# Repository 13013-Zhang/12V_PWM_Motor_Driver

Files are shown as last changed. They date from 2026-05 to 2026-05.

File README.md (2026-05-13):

# 12V DC Motor Driver Board (PWM)

> **University of Warwick · School of Engineering · ES2J1 Electrical and Electronic Design Project · 2025–2026**

A fully analogue, hardware-based educational PCB demonstrator for teaching PWM generation, DC/DC power conversion, and bidirectional DC motor control. No microcontroller or Arduino is used — all control is implemented in discrete analogue hardware.

---

## 📸 PCB Photos

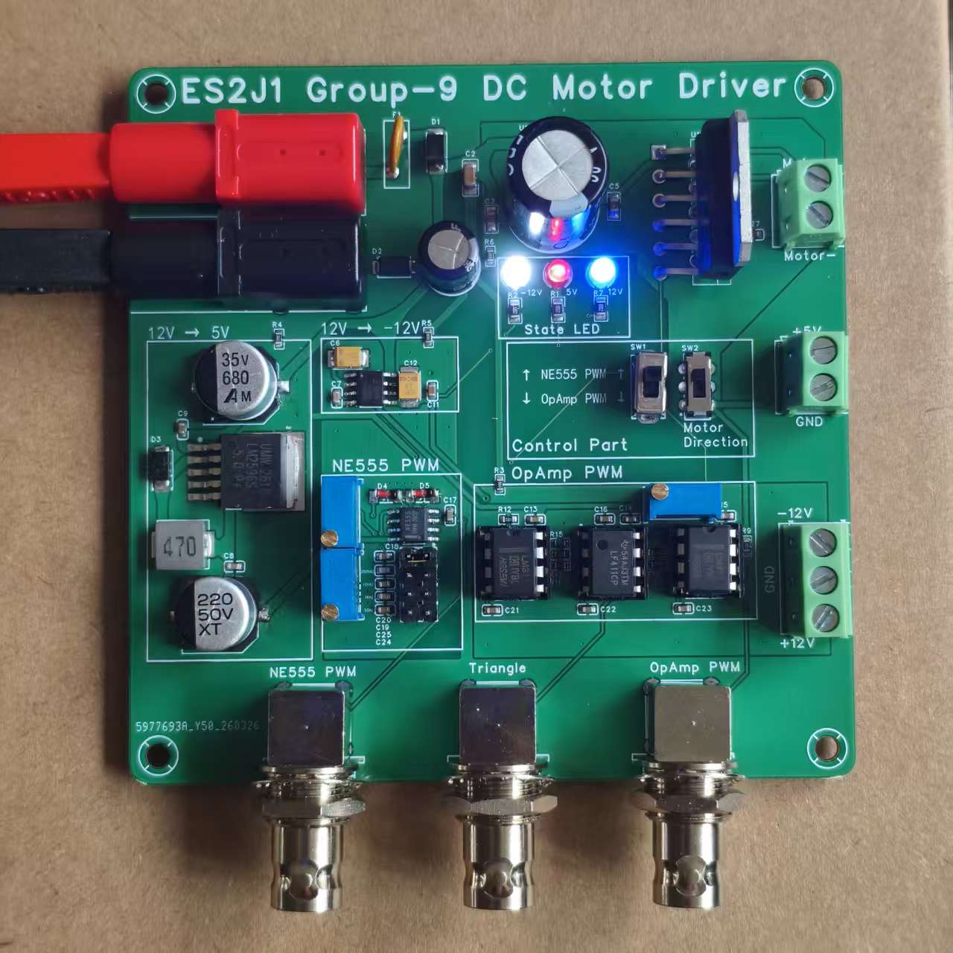
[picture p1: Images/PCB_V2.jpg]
PCB V2


---

## 🎯 Project Overview

This board was designed as a laboratory teaching tool for second-year undergraduate electrical and electronic engineering students. It integrates five functional sub-systems on a single custom 2-layer PCB, allowing students to observe, measure, and compare real hardware behaviour against theoretical predictions.

**Key design constraints met:**
- Single **+12V** supply input only
- **No microcontroller** — fully analogue PWM generation
- Custom PCB designed in **Altium Designer** (no commercial kits)
- Total component cost: **£173.36** (within £200 budget)
- Complies with **IPC-A-610G** soldering standards and **BS EN 61010** safety requirements

---

## 🗂️ Repository Structure

```
ES2J1_Group9_Motor_Driver/
│
├── PCB/
│   ├── ES2J1_Group9_Motor_Driver.PrjPcb      # Altium Designer project file
│   ├── ES2J1_Group9_Schematic.SchDoc         # Full schematic capture
│   ├── ES2J1_Group9_PCB.PcbDoc               # PCB layout and routing
│
├── Images/
│   ├── PCB_V1.jpg                        # Assembled PCB photo (V1)
│   └── PCB_V2.jpg                        # Assembled PCB photo (V2)
│
├── videos/                               # Test and demonstration videos
│   ├── NE555 OCR.mp4
│   ├── OpAmp OCR.mp4
│   ├── Simulation & Circuit.mp4
│   └── Simulation with Osc.mp4
│
└── README.md
```

---

## ⚙️ System Architecture

The board accepts a single **+12V / GND** input and generates all other required voltages on-board. Five sub-systems work together to drive and control a DC motor:

```
+12V Input
    │
    ├──► DC/DC Buck Converter (LM2596S-5.0) ──► +5V rail (NE555 supply)
    │
    ├──► Charge Pump (ICL7660AIBAZA-T) ──────► −12V rail (Op-Amp supply)
    │
    ├──► NE555 PWM Generator ─────────────────────┐
    │                                             ├──► H-Bridge (L6203) ──► DC Motor
    └──► Op-Amp PWM Generator (LF411CP / LM311N) ─┘
              (selectable via SW1)
```

### Sub-system Summary

| Sub-system | Key Component | Function |
|---|---|---|
| DC/DC Buck Converter | LM2596S-5.0 (UMW) | +12V → +5V |
| Charge Pump | ICL7660AIBAZA-T (Renesas) | +12V → −12V |
| NE555 PWM Generator | NE555D (TI) + Potentiometer | Variable duty cycle PWM |
| Op-Amp PWM Generator | LF411CP + LM311N ×2 | Triangle wave + comparator PWM |
| H-Bridge Motor Driver | L6203 (STMicroelectronics) | Bidirectional motor control |
| Protection & Thermal Mgmt | MF-R110, SMAJ18CA, heatsink | Overcurrent & transient protection |

---

## 📐 Design Details

### DC/DC Buck Converter — LM2596S-5.0
- Switching frequency: **~150 kHz** (measured: 148 kHz)
- Output voltage: **+5.00V** (measured: +4.991V, error: 0.18%)
- Output ripple: **24 mV pk-pk** (spec: <50 mV)
- Efficiency ~80% — chosen over a linear regulator (7805) to minimise PCB heat dissipation

### Charge Pump — ICL7660AIBAZA-T
- Generates **−12V** from +12V with no inductors (capacitor-based inversion)
- Measured output: **−11.32V** (5.66% deviation due to downstream IC quiescent load)
- Supplies two LM311N comparators and one LF411CP op-amp

### NE555 PWM Generator
- Configured in **astable mode** with diode-modified charging paths for near-50% duty cycle
- Measured frequency: **846.6 Hz** at mid-potentiometer setting
- Theoretical: 910.8 Hz (7.05% error — attributable to component tolerances)
- Output amplitude: **4.95V pk-pk** (Vcc = 5V)

### Op-Amp PWM Generator — LF411CP / LM311N
- **LF411CP** integrator produces a triangular wave (frequency set by R14 × C18)
- **LM311N** comparator converts triangle wave against DC reference to PWM
- Duty cycle is **linearly proportional** to reference voltage — superior linearity vs NE555
- Measured PWM frequency: **71.90 kHz**, duty cycle: **50.14%** at mid-setting
- Both triangle wave and PWM brought out to **dedicated BNC connectors**

### H-Bridge Motor Driver — L6203
- Full-bridge topology supports **bidirectional** motor control
- Peak output current: **5A**
- Direction controlled by DPDT slide switch (SW2: MSS22D18G2) swapping IN1/IN2 logic
- Protection: LL4148 flyback diodes (D4, D5) + TVS diode (SMAJ18CA) on input rail

---

## 🧪 Test Results Summary

| Test | Parameter | Expected  | Measured | Error |
| --- | --- | --- | --- | ----- |
| DC Rail — +5V  | Output voltage | +5.00 V | +4.991 V | 0.18% |
| DC Rail — −12V | Output voltage | −12.00 V  | −11.32 V | 5.66% |
| Buck Converter | Switching frequency | 150 kHz | 148 kHz | 1.3%  |
| Buck Converter | Output ripple | <50 mV | 24 mV | — |
| NE555 PWM | Frequency | 910.8 Hz  | 846.6 Hz | 7.05% |
| NE555 PWM | Duty cycle (mid) | ~50% | 47.60% | 4.8%  |
| Op-Amp PWM | Duty cycle (mid) | 50% | 50.14% | 0.28% |
| H-Bridge | Motor direction | Fwd / Rev | ✅ Confirmed | — |

---

## 🛡️ Protection Features

| Protection | Component | Purpose |
|---|---|---|
| Overcurrent | MF-R110 resettable fuse | Disconnects circuit on excessive current |
| Transient overvoltage | SMAJ18CA TVS diode | Suppresses +12V rail voltage spikes |
| Inductive kickback | LL4148 signal diodes (D4, D5) | Protects H-bridge from motor back-EMF |
| Thermal management | Switching regulator + PCB trace sizing | Wide traces on high-current paths; component spacing |

---

## 🖥️ PCB Design

- **Tool:** Altium Designer (2-layer PCB)
- **Design rules:** Compact SW node for EMI reduction; decoupling caps within 1mm of IC pins; power traces ≥1mm for paths >500mA
- **BNC connectors** (U4, U5, U6) placed at board edge for direct oscilloscope access
- **Silkscreen labels** on all functional blocks for student usability
- Manufactured externally (Week 24); assembled and tested in supervised lab sessions (Weeks 30–31)
- All solder joints inspected to **IPC-A-610G** standard

---

## 💰 Bill of Materials Summary

| Category | Lines | Total Cost (£) |
|---|---|---|
| Capacitors | 28 | £59.61 |
| Resistors (incl. 3× potentiometers) | 17 | £8.70 |
| Active ICs | 6 | £36.24 |
| Diodes & Fuse | 6 | £29.42 |
| Connectors & Switches | 11 | £26.84 |
| Inductor, Bead, LEDs | 5 | £12.55 |
| **TOTAL** | **73** | **£173.36** |

> or

| Category | Quantities | Total Cost (¥ RMB) |
| --- | --- | --- |
| Capacitors | 28 | ¥65.57 |
| Resistors | 17 | ¥12.93 |
| Active ICs | 6 | ¥84.28 |
| Diodes & Fuse | 6 | ¥20.72 |
| Connectors & Switches  | 11 | ¥67.21 |
| Inductors, Bead & LEDs | 5 | ¥10.17 |
| **合计 TOTAL** | **47** | **¥260.98** |

---

## 👥 Team

| Member | Key Contributions |
|---|---|
| **Boyu Zhang (Bob)**  | Team Leader · Project Manager · Buck Converter · Charge Pump · H-Bridge · Schematic · PCB Layout · Soldering · Testing |
| **Jiaye Yu**  | NE555 PWM Design · Soldering · Testing |
| **Adam Ward**  | Op-Amp PWM Circuit · Soldering |
| **Zhenyu Tang**  |  |
| **Arav Sharma**  | Protection & Thermal Management · Soldering |

**Project Director:** Dr Jose Ortiz Gonzalez, School of Engineering, University of Warwick

---

## 📚 Key References

1. Texas Instruments, *LM2596 SIMPLE SWITCHER® Power Converter*, SNVS124G, Mar. 2023.
2. Renesas Electronics, *ICL7660S, ICL7660A*, FN3179, Rev 7.01, Feb. 2020.
3. STMicroelectronics, *L6203 DMOS Full-Bridge Driver*, 2003.
4. Texas Instruments, *LF411 Low Offset, Low Drift JFET Input Op-Amp*, 2015.
5. Texas Instruments, *LM311 Voltage Comparator*, 2015.
6. Texas Instruments, *xx555 Precision Timers*, SLFS022K, Mar. 2026.
7. IPC, *IPC-A-610G: Acceptability of Electronic Assemblies*, 2017.
8. BSI, *BS EN 61010-1:2010: Safety Requirements for Electrical Equipment*, 2010.

---

## 📄 License

This project was developed for educational purposes as part of the ES2J1 module at the University of Warwick. All design files are shared for reference and learning.

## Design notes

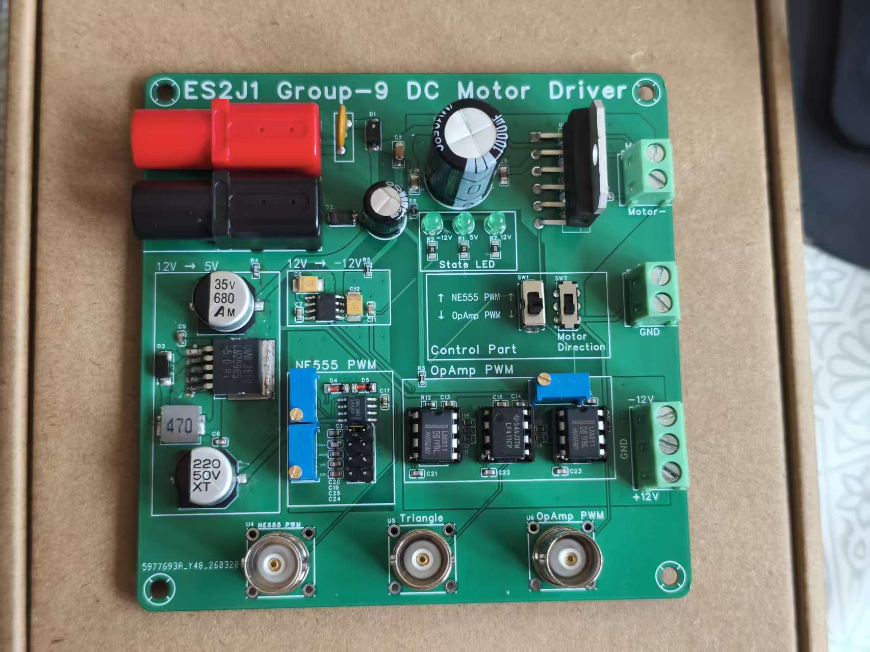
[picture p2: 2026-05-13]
Images/PCB_V1.jpg
